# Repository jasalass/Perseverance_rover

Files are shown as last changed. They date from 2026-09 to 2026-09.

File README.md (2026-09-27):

# Rover Percy

🏆 **1er lugar — Torneo Arena IV 2026, Duoc UC** (Desafío de Innovación
CITT-2026, Misión EREBUS-I: Exploración Planetaria).

👥 **Equipo:** Pamela Alvarez y Juan Salas

## 📺 Mira el video

<p align="center">
  <a href="https://youtu.be/7GjuUFy00kE">
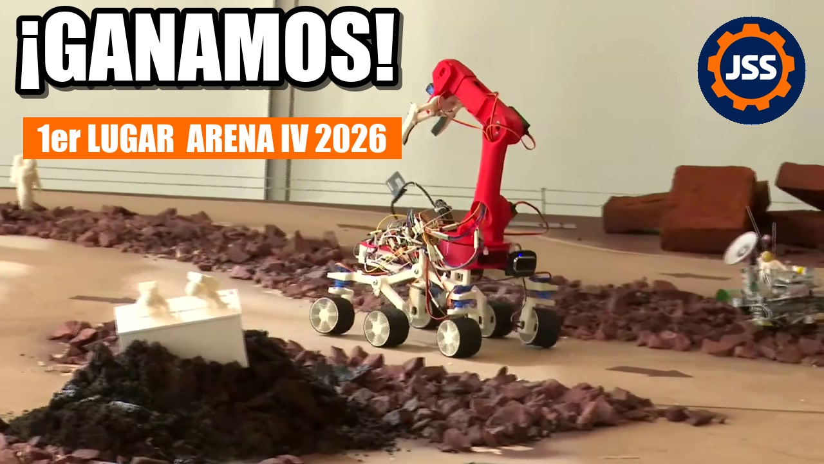
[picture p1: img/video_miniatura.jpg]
Video: Percy compitiendo y la premiación del 1er lugar (clic para ver en YouTube)
    
  </a>
  <br>
  <sub><a href="https://youtu.be/7GjuUFy00kE">Ver en YouTube</a>: Percy en la pista y la premiación.
  Transmisión completa del torneo en el
  <a href="https://www.youtube.com/watch?v=aI01HbEa-U4">canal de Duoc UC</a>.</sub>
</p>

---

## En pocas palabras

Percy es un robot explorador de 6 ruedas inspirado en el rover
*Perseverance* de la NASA. En la competencia tenía que cruzar una pista
de 4×4 m con arena, gravilla y rocas que simula la superficie de Marte,
**recoger muestras con su brazo robótico** y llevarlas a una zona de
depósito, todo en menos de 10 minutos.

<p align="center">
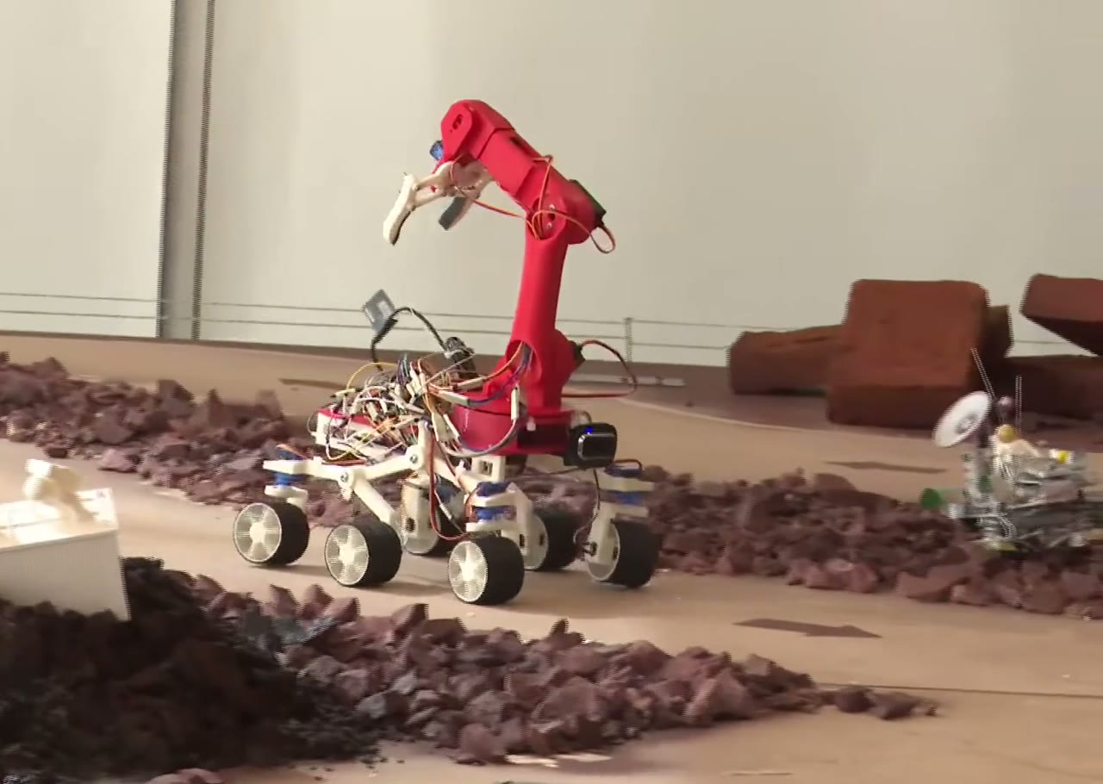
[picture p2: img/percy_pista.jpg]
Percy en la pista de competencia, con la garra abierta
  
</p>

Se maneja **desde el celular**, sin instalar ninguna aplicación: el
robot crea su propia red WiFi, uno se conecta y abre una página web con
dos joysticks táctiles, uno para conducir y otro para mover el brazo.

<p align="center">
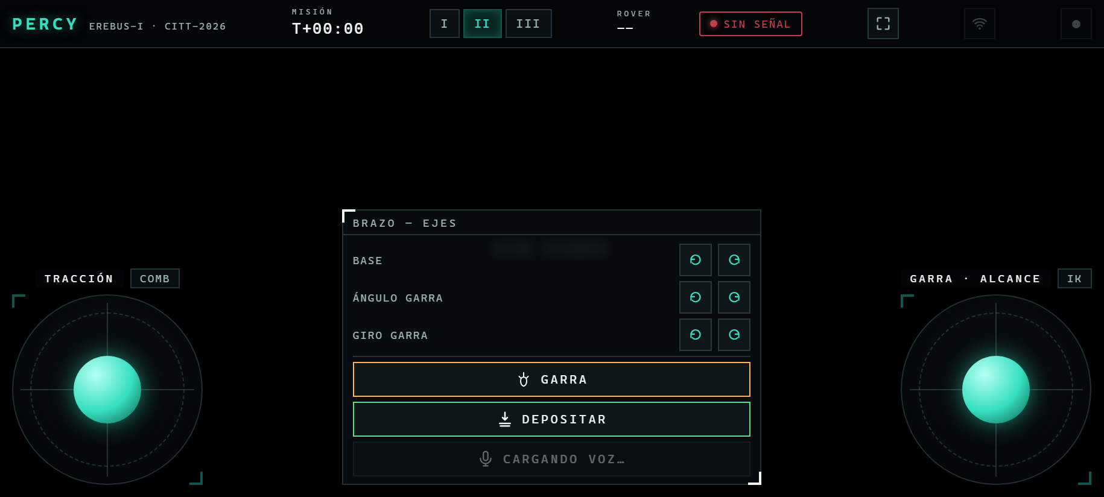
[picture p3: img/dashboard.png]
Dashboard de control en el celular: joystick de tracción a la izquierda, joystick del brazo a la derecha y botones de garra al centro
  
  <br>
  <sub>El panel de control en el celular (horizontal). Joystick izquierdo: tracción. Joystick derecho: punta de la garra. Al centro, los ejes del brazo, la garra y el depósito. El video de la cámara va de fondo.</sub>
</p>

Casi todo el robot está **impreso en 3D**: ruedas, suspensión, chasis y
brazo.

## ¿Cómo funciona?

| Parte | Qué hace |
|---|---|
| **Suspensión rocker-bogie** | El mismo sistema de los rovers reales de Marte: las ruedas suben y bajan por separado, así el robot pasa sobre rocas sin volcarse. |
| **Chasis rediseñado y alargado** | El Percy original no tenía brazo. Alargamos el chasis cerca de un 50% (de 14 a 21 cm) para que el brazo quepa arriba sin desequilibrar el rover, y diseñamos una base nueva que une los dos costados del chasis y sostiene el brazo. |
| **6 ruedas con motor** | Las 6 ruedas empujan, y las 4 de las esquinas además giran para doblar (ver "¿Cómo se desplaza?" abajo). |
| **Brazo robótico con garra** | Gira, sube, baja y se estira para tomar muestras, y las lleva sujetas en la garra hasta la zona de depósito. El operador mueve la punta de la garra con el joystick y el robot calcula solo cómo mover cada articulación. |
| **Computador a bordo** | Una Orange Pi 3B (similar a una Raspberry Pi) recibe las órdenes del celular y controla todos los motores. |
| **Dos baterías separadas** | Una para el computador y otra para los motores, para que un tirón de corriente de los motores no reinicie el computador en plena misión. |

<p align="center">
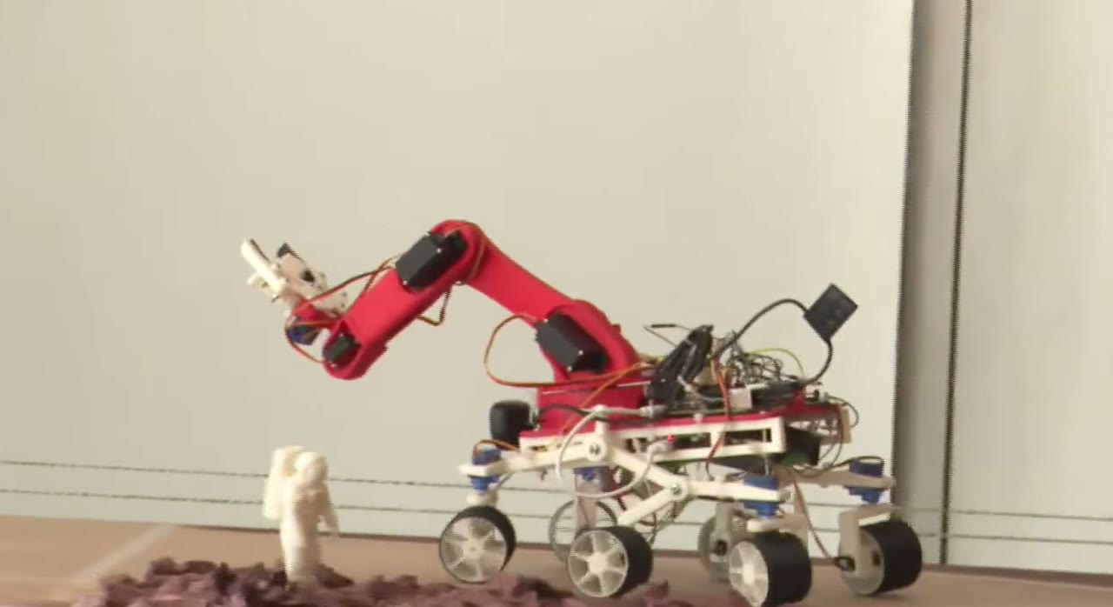
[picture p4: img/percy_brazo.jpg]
Vista lateral de Percy con el brazo extendido
  
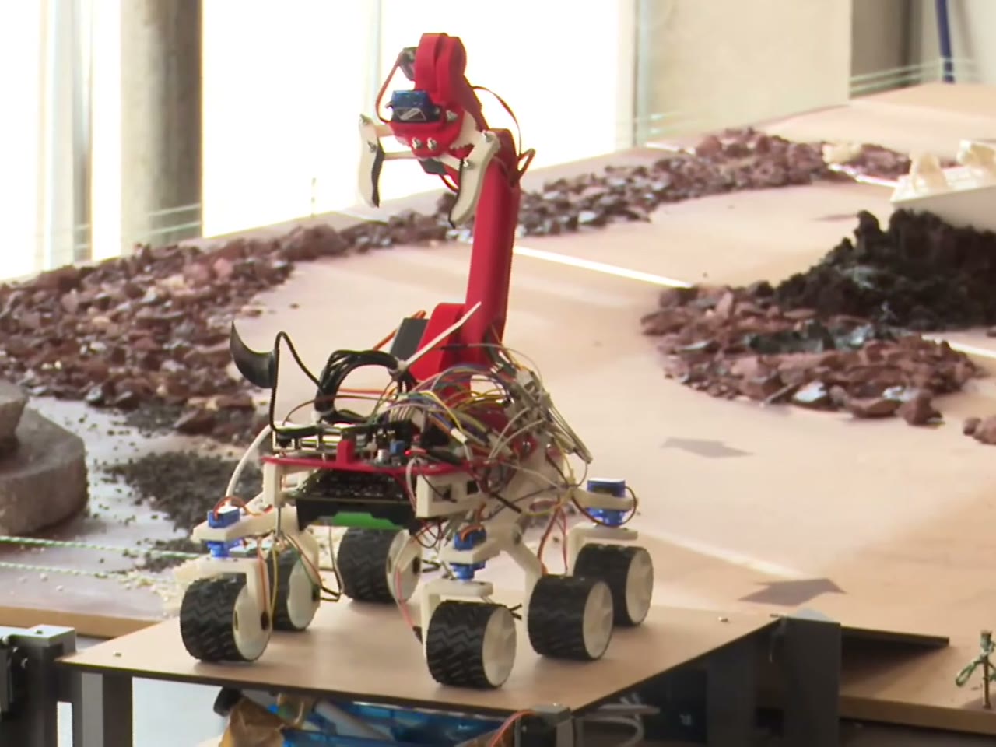
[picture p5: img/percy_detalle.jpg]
Primer plano de Percy: suspensión rocker-bogie, electrónica y brazo
  
</p>

## ¿Cómo se desplaza?

Cada una de las 6 ruedas tiene su propio motor, y las 4 de las esquinas
tienen además un pequeño servo que las hace girar, como el volante de
un auto pero en las dos puntas del robot. Con el joystick izquierdo se
acelera, se frena y se dobla, y un botón del celular cambia entre tres
formas de manejar:

| Modo | Cómo dobla | Para qué sirve |
|---|---|---|
| **Combinado** (el normal) | Gira las ruedas de las esquinas y además hace que un lado avance más rápido que el otro | Uso general: dobla cerrado y firme |
| **Vehículo** | Solo gira las ruedas, como un auto | Arena suelta: las ruedas no se arrastran de costado |
| **Tanque** | Pone las 4 ruedas de las esquinas en diagonal y hace girar cada lado hacia un sentido opuesto | Girar sobre su propio eje sin avanzar, para acomodarse frente a una muestra en poco espacio |

También hay tres velocidades (lenta, media y rápida): la lenta sirve
para acercarse con precisión a una muestra y la rápida para cruzar la
pista.

## Extras de innovación
- El celular **vibra** al agarrar una muestra o cuando el brazo llega a
  su límite.
- **Grabar y reproducir posiciones del brazo:** el operador deja el
  brazo en una posición (por ejemplo, "lista para tomar" o "traslado"),
  la graba con un nombre desde el celular, y después el
  brazo vuelve a ella solo, con un movimiento suave, apretando un botón.
  Ahorra tiempo en las maniobras que se repiten en cada viaje.
- Prototipo de **control por voz** que funciona sin internet, dentro
  del mismo navegador.

---

## Detalle técnico

### Arquitectura

```
Celular (navegador) --WebSocket /ws--> FastAPI (Orange Pi 3B)
                                          |-- I2C  --> PCA9685 --> 10 servos (brazo, garra, steering)
                                          '-- GPIO --> 2x TB6612FNG --> 6 motores N20 (tracción)
```

- **Cómputo:** Orange Pi 3B (RK3566, 4GB) con Ubuntu 22.04 oficial,
  Python + FastAPI + WebSocket. El dashboard es HTML/JS plano, sin
  dependencias externas (en pista no hay internet).
- **Red:** se conecta a redes WiFi conocidas o, si no encuentra
  ninguna, levanta su propia red. Accesible también como `percy.local`.
- **Chasis:** los `side_chassis` originales de BricoLabs (140 mm) se
  reemplazaron por `chasis_largo` (211 mm, ~50% más largos) para ganar
  espacio para el brazo y la electrónica. El brazo se integra con una
  base propia (`base_brazo`, 120×217 mm) que se atornilla sobre los dos
  largueros y reemplaza la `Base.STL` del tutorial; la cintura (`Waist`)
  y el servo de giro se montan encima sin cambios. Piezas en
  `3dprint/stl/rover_perceverance/canasta - chasis nuevo/`.
- **Brazo:** piezas originales del
  [HowToMechatronics](https://howtomechatronics.com/tutorials/arduino/diy-arduino-robot-arm-with-smartphone-control/),
  sin rediseñar, montadas sobre una base propia atornillada al chasis.
  3 servos MG996R (base, hombro, codo) + 1 SG90S con engranajes
  metálicos (inclinación de muñeca) + 2 MG90S (giro y cierre de garra).
  Hombro, codo e inclinación se controlan por cinemática inversa de 3
  juntas acopladas: el joystick mueve la punta de la garra en línea
  recta, no articulación por articulación. También tiene un modo libre
  (articulación por articulación) para calibrar.
- **Presets del brazo:** se graban desde el dashboard con nombre
  (`preset_save`), se reproducen (`preset_goto`) y se borran
  (`preset_delete`) por el mismo WebSocket. Guardan el ángulo final de
  los 5 servos del brazo en `presets.json`, no el trayecto. Al
  reproducirlos, el brazo rampea a 60°/s desde donde esté hasta la pose
  guardada.
- **Dirección:** 4 servos SG90 en las esquinas (±35° en manejo normal),
  con las traseras girando al revés que las delanteras para cerrar el
  radio de giro. 3 modos seleccionables (`drive_mode`): combinado
  (dirección + diferencial entre lados), vehículo (solo dirección) y
  tanque (pivote de radio cero real: ruedas en rombo a 52,5°, ángulo
  calculado de la trocha de 18 cm y la distancia entre ejes de 23,5 cm,
  más diferencial en sentidos opuestos). 3 niveles de velocidad (45%,
  65% y 100% del PWM máximo).
- **Tracción:** 6 motores N20 (1:150) vía 2 puentes H TB6612FNG
  (4 canales, con motores en paralelo por lado), con señal de dirección
  por GPIO y PWM de velocidad por canales libres del PCA9685 (no por los
  2 únicos PWM de hardware de la Orange Pi).
- **Alimentación:** rail de cómputo aislado (2×18650 → módulo 5V USB)
  separado del rail de actuadores (3×18650 → LM2596 → 6V, servos +
  motores), con un interlock por software que corta la tracción
  mientras el brazo se mueve, por el presupuesto de corriente compartido.
- **Control por voz:** Vosk compilado a WebAssembly, 100% en el
  navegador y con gramática cerrada para resistir el ruido de pista.
  Probado offline en PC; en el celular requiere servir el dashboard por
  HTTPS.

### Documentación

- **[`orangepi/README.md`](orangepi/README.md):** protocolo WebSocket,
  tabla de pines y cableado, calibración del brazo, endpoints REST,
  instalación y estructura del código. Incluye una guía de uso del panel
  de control.
- **[`orangepi/voice_models/README.md`](orangepi/voice_models/README.md):**
  cómo generar el modelo de voz para el control por voz.

### Estructura del repo

```
orangepi/       backend (FastAPI, servos, motores, dashboard) - ver su README
3dprint/        piezas STL/gcode del chasis, brazo y ruedas
img/            fotos y capturas usadas en este README
```

## Créditos

- Base mecánica adaptada de [Percy de BricoLabs](https://github.com/felixstdp/Perseverance)
  (rocker-bogie 1:10).
- Brazo del tutorial [DIY Arduino Robot Arm de HowToMechatronics](https://howtomechatronics.com/tutorials/arduino/diy-arduino-robot-arm-with-smartphone-control/).
- Electrónica, software de control y dashboard propios.
- Fotos del rover: fotogramas de la [transmisión oficial de Duoc UC](https://www.youtube.com/watch?v=aI01HbEa-U4)
  del Torneo Arena IV 2026.

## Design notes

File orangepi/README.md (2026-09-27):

# Percy — software de control (Orange Pi 3B)

Esta carpeta es el "cerebro" del rover: el programa que corre en la
Orange Pi y la página web que se abre en el celular para manejarlo. Ver
el [README principal](../README.md) para el contexto del proyecto
(concurso, mecánica, hardware).

## En pocas palabras

- El rover lleva a bordo una **Orange Pi 3B**, un computador del tamaño
  de una tarjeta de crédito (parecido a una Raspberry Pi).
- En ella corre un **servidor web**. Cuando uno abre esa página en el
  celular, aparece un panel de control con joysticks táctiles.
- Cada movimiento del joystick viaja por WiFi al rover unas 20 veces por
  segundo, y la Orange Pi lo convierte en órdenes para los motores de
  las ruedas y los servos del brazo.
- No hace falta instalar ninguna aplicación ni tener internet: basta con
  el navegador del celular.

## Cómo se usa

1. **Encender el rover.** El programa arranca solo; no hay que hacer nada
   más.
2. **Conectar el celular al rover.**
   - En casa, el rover se conecta a las redes WiFi que tenga guardadas.
   - En cualquier otro lugar, si en ~1 minuto no encuentra una red
     conocida, crea su **propia red WiFi, `PercyRover`**.
3. **Abrir el panel** en el navegador del celular:
   - Con la red propia: `http://10.42.0.1:8000`
   - En otra red: `http://percy.local:8000`, o la IP que muestra el aviso
     del rover (ver "WiFi" más abajo).
4. **Poner el celular en horizontal** y manejar con los dos pulgares.

<p align="center">
  Panel de control: joystick de tracción a la izquierda, joystick del brazo a la derecha, botones del brazo al centro
</p>

| Control | Qué hace |
|---|---|
| **Joystick izquierdo** (TRACCIÓN) | Avanza, retrocede y dobla |
| Botón **COMB** junto al joystick izquierdo | Cambia el modo de manejo: combinado, vehículo o tanque (girar en el lugar) |
| **I / II / III** (arriba) | Velocidad lenta, media o rápida |
| **Joystick derecho** (GARRA · ALCANCE) | Mueve la punta de la garra: arriba/abajo y adelante/atrás |
| Botón **IK / LIBRE** junto al joystick derecho | IK: la garra se mueve en línea recta. LIBRE: cada articulación por separado |
| **BASE** | Gira todo el brazo a la izquierda o derecha |
| **ÁNGULO GARRA** | Inclina la garra hacia arriba o abajo |
| **GIRO GARRA** | Gira la garra sobre sí misma |
| **GARRA** | Abre o cierra la garra |
| **DEPOSITAR** | Lleva el brazo a la posición de soltar, abre la garra y vuelve |
| **Micrófono** (VOZ) | Mantener apretado y decir un comando (ver "Control por voz") |
| Ícono de **grabar** (arriba) | Guardar la posición actual del brazo con un nombre, o volver a una guardada |
| Ícono de **WiFi** (arriba) | Ver y cambiar la red del rover |

El celular **vibra** al abrir o cerrar la garra, al depositar y cuando el
brazo llega a su límite.

**Consejos:**
- **Un solo celular conectado a la vez.** Si hay dos, se pisan las
  órdenes (el que está quieto manda "parar").
- **Apagar bien:** `sudo poweroff`, no cortar la batería de golpe. La
  tarjeta SD guarda con retraso y un corte puede perder cambios
  recientes.
- **Cablear siempre con las dos baterías desconectadas.**

---

## Detalle técnico

### Instalación en la Orange Pi

Probado con **Ubuntu 22.04 Server**, imagen oficial de orangepi.org para
la 3B.

```bash
# copiar la carpeta completa a la Orange Pi (desde el PC, con pscp/scp)
pscp -r orangepi orangepi@<ip-orange-pi>:/home/orangepi/percy

# en la Orange Pi
cd ~/percy
pip3 install --user -r requirements.txt   # ver nota en requirements.txt:
                                           # NO instala opencv/gpiod (ya son del sistema)
sudo sh wifi/install.sh                    # gestor WiFi + red propia (ver "WiFi")
```

Después de copiar archivos, correr `sync` antes de apagar.

**Arranque automático (systemd).** El servidor corre como servicio
(`/etc/systemd/system/percy.service`, copia en `percy.service`) y
arranca solo en cada reinicio:

```bash
sudo systemctl status percy.service   # ver estado
sudo systemctl restart percy.service  # reiniciar tras un cambio de codigo
sudo journalctl -u percy.service -f   # ver logs en vivo
```

Tras copiar código nuevo hay que reiniciar el servicio. No lanzar
`python3 main.py` a mano: quedaría un segundo proceso compitiendo por el
puerto 8000.

### Arquitectura y protocolo

```
Celular (navegador) --WebSocket /ws--> FastAPI (main.py)
                                          |-- I2C --> PCA9685 --> 10 servos + PWM de motores (ch10-15)
                                          |                       (brazo x4, giro garra, garra, steering x4)
                                          '-- GPIO --> 2x TB6612FNG --> 6 motores N20 (en paralelo por lado)
```

El dashboard manda ~20 mensajes/seg por WebSocket con el estado completo
de joysticks/botones (no solo cambios). `main.py:_apply_command` traduce
cada mensaje a servos/motores; el servidor responde con un eco liviano
(`{"hit_limit": bool}`) que el dashboard usa para el feedback háptico.

### Tracción — 3 modos (botón de modo del dashboard, `drive_mode`)

| Modo | Cómo gira | Cuándo conviene |
|---|---|---|
| `combinado` (default) | Las 4 ruedas de esquina giran proporcional a `lx` **y** además hay diferencial de velocidad entre lados con el mismo `lx` | Uso general |
| `vehiculo` | Solo dirigen las ruedas de esquina (los 2 lados a la misma velocidad, como un auto) | Terreno suelto: menos desgaste, pero necesita más espacio para girar |
| `tanque` | Diferencial entre lados **+** las 4 ruedas en diagonal, patrón de rombo (ver `servos.set_pivot_steering`) | Pivote de radio cero real, sin arrastrar las ruedas de costado. El ángulo (52,5°) sale de las medidas del chasis (18 cm de trocha, 23,5 cm entre ejes) |

En `combinado`/`vehiculo` las ruedas **traseras giran al revés que las
delanteras**, para cerrar el radio de giro. En `tanque` el rombo es el
mismo para los dos sentidos de giro (se usa `abs(lx)`; el sentido lo pone
el diferencial).

Velocidad: `config.SPEED_LEVELS` multiplica el PWM máximo (45% / 65% /
100%).

### Brazo — cinemática inversa de 3 juntas acopladas

El brazo son las piezas originales del HowToMechatronics, sin rediseñar.
Base, hombro y codo van en MG996R; la inclinación de la muñeca (ch3) va
en un **SG90S con engranajes metálicos**; giro y cierre de garra en
MG90S. Hombro, codo e inclinación quedan en el mismo plano vertical.
`kinematics.solve3(x_mm, y_mm, phi_deg, elbow_up)` calcula los 3 ángulos
de servo necesarios para poner la punta de la garra en esa posición
**con ese ángulo de acercamiento**, no solo esa posición.

Dos modos, elegidos con el switch del dashboard (`arm_mode`):

- **`ik` (default):** el joystick derecho mueve la punta de la garra en
  línea recta (`arm_x_dir`/`arm_y_dir` = velocidad cartesiana, no
  ángulo), y los botones de ángulo de garra mueven el ángulo de
  acercamiento (`wrist_dir` → `phi_dir`). Si el punto pedido no es
  alcanzable, o algún ángulo de servo cae fuera de rango, el objetivo se
  congela en el último punto válido ("pared blanda") en vez de saltar o
  clampear.
- **`joint` (LIBRE):** mismos 3 ejes, pero cada uno mueve su articulación
  por separado (vertical → hombro, horizontal → codo, botones →
  inclinación). Útil para calibrar o alcanzar posiciones que la IK no
  puede.

Si el punto pedido cabe pero el ángulo de acercamiento no (la
inclinación tiene rango corto y suele ser la primera en tocar tope),
**se prioriza la posición de la punta** y se suelta el ángulo lo mínimo
necesario. Además hay una **guarda anti-latigazo**
(`config.IK_MAX_JOINT_STEP_DEG = 8`): una solución que pida mover una
junta más de 8° en un solo tick se rechaza.

**Giro de garra** (canal 4): eje independiente de la IK (girar la garra
no mueve la punta), con sus propios botones (`gripper_rotate_dir`).
Centro en 90°.

Calibración (en `config.py`):

| Junta | Cero (horizontal) | Escala/signo | Rango servo |
|---|---|---|---|
| Hombro (ch1) | 90° | +1 | 45°–175° |
| Codo (ch2) | 68° (horn movido 3 dientes) | −1.19 | 10°–175° |
| Inclinación (ch3, SG90S metálico) | 30° (horn movido 1 diente) | +1 | 5°–135° |
| Giro garra (ch4) | 90° = derecha | — | 10°–170° |

Largos: L1 = 120 mm (medido); **L2 = 115 / L3 = 135 mm estimados** (suman
los 250 mm medidos de codo a punta).

**Presets** (`presets.py`): guardan el ángulo final de los 5 servos del
brazo bajo un nombre, no el camino ni el tiempo. Al pedir un preset
(`preset_goto`), el brazo rampea suave (60°/s) desde donde esté hasta
esos ángulos. `preset_save`/`preset_delete` completan el CRUD;
`/presets` lista los nombres. Quedan en `presets.json`.

**Macro "depositar"** (`servos.deposit_macro`): mueve el brazo a la pose
de depósito (`DEPOSIT_*`), abre la garra y vuelve a la posición de
espera. La muestra viaja en la garra y se suelta directo en la zona de
depósito. Bloqueante, en 3 pasos fijos, sin coordinación con la IK.

### Interlock brazo/tracción

Los 3 MG996R del brazo y los 6 N20 de tracción comparten el mismo riel
de 6V (LM2596 + 3×18650), sin margen de corriente medido para mover los
dos a fondo a la vez. Mientras el brazo esté pedido a moverse, todavía
decelerando, o un preset/macro de depósito esté en curso, `main.py`
fuerza la potencia de los N20 a 0 (la dirección sigue funcionando: son
SG90 de bajo consumo). Expuesto en `/status` como `arm_busy`.

### Feedback háptico

El dashboard vibra el celular al cerrar/abrir garra, disparar el
depósito, reconocer un comando de voz, y en el flanco ascendente de
`hit_limit` (el brazo empujando contra un límite: pared blanda de la IK
o tope de articulación en modo LIBRE).

### Control por voz

Reconocimiento de voz **100% local en el navegador** (Vosk compilado a
WebAssembly, `vosk-browser`): el audio nunca sale del celular ni depende
de internet. Es un modelo acústico real (TDNN); lo que lo hace robusto
al ruido de pista es una **gramática cerrada** en vez de reconocimiento
abierto. Solo puede decidir entre estas 7 frases:

```
"abrir garra", "cerrar garra", "depositar",
"posicion inicial", "traslado", "parar", "alto"
```

Push-to-talk (mantener apretado el botón, no "siempre escuchando"):
`getUserMedia` abre el micrófono → `AudioContext`/`ScriptProcessor`
cortan el audio en bloques de 4096 muestras → `KaldiRecognizer` en
tiempo real → si el resultado final coincide exacto con una frase,
dispara la acción (grip, deposit, preset_goto, o "parar", que corta
joysticks y botones de eje).

**Requisitos:** `getUserMedia` exige HTTPS o `localhost` (ver "HTTPS"),
y el modelo (`model.tar.gz`, ~40MB) tiene que estar en `static/voice/`.
Cómo generarlo: [`voice_models/README.md`](voice_models/README.md).
Probado offline en PC.

### Cableado de motores N20

Cada placa TB6612FNG tiene su **propio** par IN1/IN2 por GPIO dedicado y
su propio canal PWM en el PCA9685 (`servos.set_motor_pwm`, escritura
cruda por registro porque `adafruit_pca9685.duty_cycle` tira `TypeError`
en esta combinación de SO/versión). La Pi solo tiene 2 PWM de hardware
reales, por eso el PWM de motores va por el PCA9685.

- **2 placas TB6612FNG** (4 canales) para los 6 motores. Se usan 3 de
  los 4 canales; el canal B de la placa 2 queda libre.
- **Motores cableados cruzados:** canal **A (AO) = motores derechos**,
  canal **B (BO) = motores izquierdos**. Se corrige en `config.py` (el
  lado izquierdo usa los pines del canal B), sin recablear.
- **Motores en paralelo por lado** (todos los de un lado reciben siempre
  el mismo comando):

| Salida | Motores |
|---|---|
| Placa 1, BO1/BO2 | izquierdos (delantero, central y trasero) |
| Placa 1, AO1/AO2 | derecho delantero |
| Placa 2, AO1/AO2 | derecho central + derecho trasero |
| Placa 2, canal B | libre |

**Señales (pines físicos del header):**

| Señal | Placa 1 | Placa 2 |
|---|---|---|
| AIN1 / AIN2 (derecha) | 11 / 12 | 26 / 31 |
| PWMA | PCA9685 ch10 | ch11 |
| BIN1 / BIN2 (izquierda) | 13 / 15 | 35 / (40, sin conectar) |
| PWMB | PCA9685 ch13 | ch14 |
| STBY | pin 16 (puenteado) | pin 16 (puenteado) |
| VCC lógica | pin 17 (puenteado) | pin 17 (puenteado) |
| VM | +6V del LM2596 | +6V del LM2596 |
| GND | tierra de potencia (estrella) | tierra de potencia (estrella) |

`config.py` define un tercer juego de líneas (pines 29/33/36/38, PCA9685
ch12/15) del diseño original de 3 placas. El software las sigue
manejando, pero no hay nada conectado ahí y no afecta.

**Revisión de la Orange Pi:** según la revisión de la placa, el **pin
físico 26** puede ser GPIO126 o GPIO135. Si se cambia de Orange Pi,
correr `gpio readall` y comparar antes de conectar.

**Tierra:** los GND de las placas van a la tierra de potencia (negativo
del LM2596), no a los pines GND de la Pi. Si se suelta el negativo de
los motores, no gira ninguno.

Si un motor gira al revés que sus compañeros de lado, invertir sus 2
cables en el borne en vez de tocar el software.

Trade-off aceptado: el PWM de motor corre a 50Hz (frecuencia fija del
PCA9685, compartida con los servos), así que puede zumbar un poco a
velocidad baja.

### WiFi: redes conocidas + red propia de respaldo

- Se conecta solo a las redes guardadas en la Pi.
- Si en ~1 minuto no logra conectarse a ninguna, el servicio
  `percy-wifi-watchdog` crea la **red propia `PercyRover`** (clave por
  defecto en `wifi/percy-wifi`, `AP_DEFAULT_PSK`; conviene cambiarla) →
  dashboard en **`http://10.42.0.1:8000`**.
- **Panel WiFi en el dashboard** (protegido con el mismo PIN que las
  posiciones): estado, buscar redes, conectarse (la clave se guarda en la
  Pi), olvidar, desconectar, y activar/apagar la red propia. Cambiar de
  red corta la conexión del celular; el panel avisa a qué red pasarse.
- Si una conexión nueva falla, la Pi vuelve a la red anterior; si tampoco
  puede, crea la red propia. Nunca queda incomunicada.
- **Encontrar el rover en una red nueva** (IP desconocida):
  - **Aviso ntfy:** cada vez que el rover queda en una red (o cambia de
    IP) publica su IP en un canal privado de ntfy; tocar la notificación
    abre el dashboard. El canal lo genera al azar `install.sh` en
    `/etc/percy-wifi-topic` (no está en el repo; se ve en el panel WiFi).
    Necesita internet en esa red.
  - **Nombre fijo:** `http://percy.local:8000` (hostname `percy` +
    avahi). Funciona en PC e iPhone; en Android no siempre.

Implementación: `wifi/percy-wifi` (script sobre `nmcli`, instalado en
`/usr/local/bin` como root; el backend lo llama con una regla `sudo`
acotada a ese único script) + `percy-wifi-watchdog.service`. Instalar con
`sudo sh wifi/install.sh`. Las claves quedan solo en la Pi
(NetworkManager), nunca en el repo. Para agregar una red a mano:
`sudo percy-wifi save "<ssid>" "<clave>"`.

### HTTPS (necesario para el control por voz)

El micrófono del celular (`getUserMedia`) solo funciona en un "contexto
seguro": `https://` o `localhost`. Se usa un certificado autofirmado:
`config.SSL_KEYFILE`/`SSL_CERTFILE` apuntan a `percy.key`/`percy.crt` en
esta carpeta. Si no existen, `main.py` arranca en HTTP plano igual (sin
voz).

Generar el certificado (**rehacerlo si cambia la IP de la Orange Pi**):

```bash
openssl req -x509 -newkey rsa:2048 -nodes -keyout percy.key -out percy.crt -days 825 \
  -subj "/CN=percy.local" \
  -addext "subjectAltName=IP:<ip-orange-pi>,DNS:localhost,IP:127.0.0.1"
```

Copiar `percy.key`/`percy.crt` junto con el resto de la carpeta. La
primera vez que el celular entra a `https://<ip-orange-pi>:8000/`, el
navegador avisa "la conexión no es privada" (normal con un certificado
autofirmado): aceptarlo una vez ("Avanzado" → "Continuar de todas
formas").

### Calibración y seguridad

Todos los pines, canales y ángulos están en `config.py`. Dirección de
las 4 esquinas: `STEER_CENTER = {"fl":85,"fr":90,"rl":85,"rr":95}`.

**Failsafe:** con `config.FAILSAFE_ENABLED = True`, si pasan ~500 ms sin
mensajes del dashboard se detienen los motores. En el repo está en
`False` para poder calibrar por curl/SSH sin el dashboard abierto:
**ponerlo en `True` antes de manejar el rover**.

### Estructura

- `config.py` - todos los pines, canales y ángulos en un solo lugar.
- `servos.py` - PCA9685: 10 servos (brazo x4, giro garra, garra,
  steering x4) por ángulo, más `set_motor_pwm` (PWM crudo de motor,
  ch10-15).
- `kinematics.py` - cinemática inversa del brazo: `solve()` (2 juntas,
  histórico) y `solve3()` (3 juntas acopladas, la que usa `main.py`).
- `presets.py` - guardar e ir a posiciones nombradas del brazo
  (`presets.json`).
- `motors.py` - 6 motores N20 vía 2x TB6612FNG (GPIO de dirección por
  placa + PWM por PCA9685).
- `camera.py` - stream MJPEG de la cámara USB (no rompe nada si no hay
  cámara).
- `main.py` - FastAPI, WebSocket `/ws`, failsafe, interlock
  brazo/tracción; sirve `static/`.
- `static/` - dashboard (2 joysticks, botones, control por voz; ver
  `app.js`).
- `wifi/` - gestor de redes y red propia de respaldo.
- `voice_models/` - cómo generar el modelo de voz y pruebas locales.

### API

#### WebSocket `/ws`

Mensaje del cliente (todos los campos opcionales, default 0/false):

```json
{
  "lx": -0.8, "ly": 0.6, "speed": 1, "drive_mode": "combinado",
  "arm_mode": "ik", "arm_x_dir": 0, "arm_y_dir": 0, "wrist_dir": 0,
  "base_dir": 0, "gripper_rotate_dir": 0, "grip": 0, "deposit": 0,
  "preset_save": null, "preset_goto": null, "preset_delete": null
}
```

Respuesta del servidor (eco liviano, una vez por mensaje recibido):

```json
{"hit_limit": false}
```

#### REST

| Endpoint | Uso |
|---|---|
| `GET /status` | failsafe, cámara disponible, `arm_mode`, `drive_mode`, `arm_busy`, `preset_moving` |
| `GET /servos` | ángulos actuales de cada servo nombrado + si está en modo simulado |
| `GET /presets` | nombres de presets guardados |
| `GET /video` | stream MJPEG de la cámara (si hay) |
| `GET /debug/set_angle?channel=&angle=` | mover un canal puntual. **Solo calibración manual, sin auth** |
| `GET /debug/preset_save?name=` | guardar preset actual sin pasar por el dashboard |

### Limitaciones conocidas y mejoras futuras

- Failsafe desactivado por defecto en el repo (ver "Calibración y
  seguridad").
- Largos L2/L3 de la IK estimados, no medidos.
- Control por voz probado offline en PC, no en el celular real.
- Sensores ToF VL53L0X e IMU MPU-9250 (navegación asistida): pines
  reservados en `config.py`, código no escrito.
- La macro "depositar" es bloqueante.
- Rail de 6V sin fusible, interruptor general ni condensadores.

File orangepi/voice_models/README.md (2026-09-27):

# Modelo de voz (control por voz)

## En pocas palabras

Percy puede recibir algunas órdenes habladas, como "abrir garra" o
"parar", además de los joysticks. El reconocimiento de voz funciona
**dentro del navegador del celular, sin internet**: el audio nunca sale
del teléfono.

Para eso el navegador necesita un **modelo de voz**, un archivo que
"sabe" reconocer español hablado. Pesa unos 40 MB, así que no se guarda
en el repositorio: hay que descargarlo y prepararlo una vez con los
pasos de abajo.

Para robustez frente al ruido, el rover solo escucha 7 frases:

```
"abrir garra", "cerrar garra", "depositar",
"posicion inicial", "traslado", "parar", "alto"
```

Se usa manteniendo apretado el botón del micrófono en el panel de
control mientras se dice el comando.

---

## Detalle técnico

### Generar el modelo

Modelo [Vosk](https://alphacephei.com/vosk/models) pequeño en español
(`vosk-model-small-es-0.42`), empaquetado como `.tar.gz` para
`vosk-browser`:

```bash
curl -L -o vosk-model-small-es.zip https://alphacephei.com/vosk/models/vosk-model-small-es-0.42.zip
unzip vosk-model-small-es.zip
tar -czf model.tar.gz vosk-model-small-es-0.42
cp model.tar.gz ../static/voice/model.tar.gz
```

Después, copiar `static/voice/model.tar.gz` a la Orange Pi junto con el
resto de la carpeta `orangepi/`.

### Requisito: HTTPS

El navegador solo da acceso al micrófono en un contexto seguro
(`https://` o `localhost`). Servido por `http://<ip>:8000`, el botón de
voz falla con "SIN PERMISO DE MIC". Ver la sección "HTTPS" de
[`orangepi/README.md`](../README.md) para generar el certificado
autofirmado.

### Archivos de esta carpeta

- `test_page.html` + `test_voice.py`: pruebas locales, no forman parte
  del dashboard. Sirvieron para validar que Vosk reconoce bien los
  comandos en español antes de integrarlo a `static/app.js`.

Estado: probado offline en PC; pendiente de probar en el celular real
con HTTPS.

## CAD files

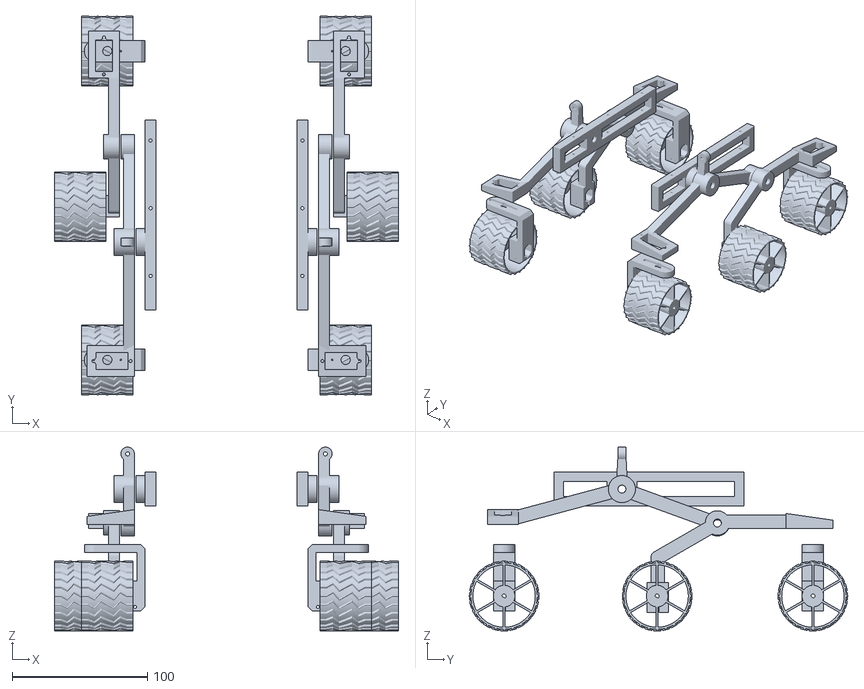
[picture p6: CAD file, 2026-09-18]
3dprint/stl/rover_perceverance/assembly.stl
254.0 x 279.5 x 135.8

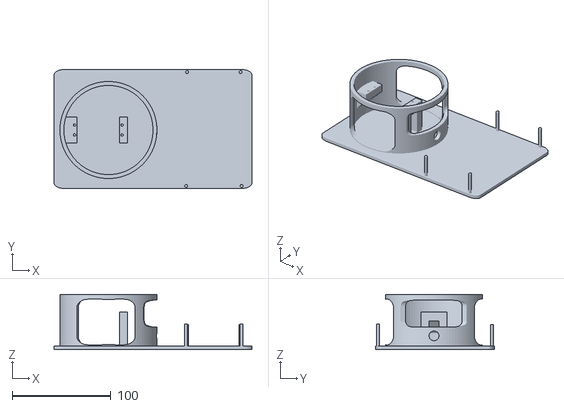
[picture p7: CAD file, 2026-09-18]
3dprint/stl/brazo_howto/bases_descartadas/base_soporte_canasta.stl
200.0 x 120.0 x 56.0

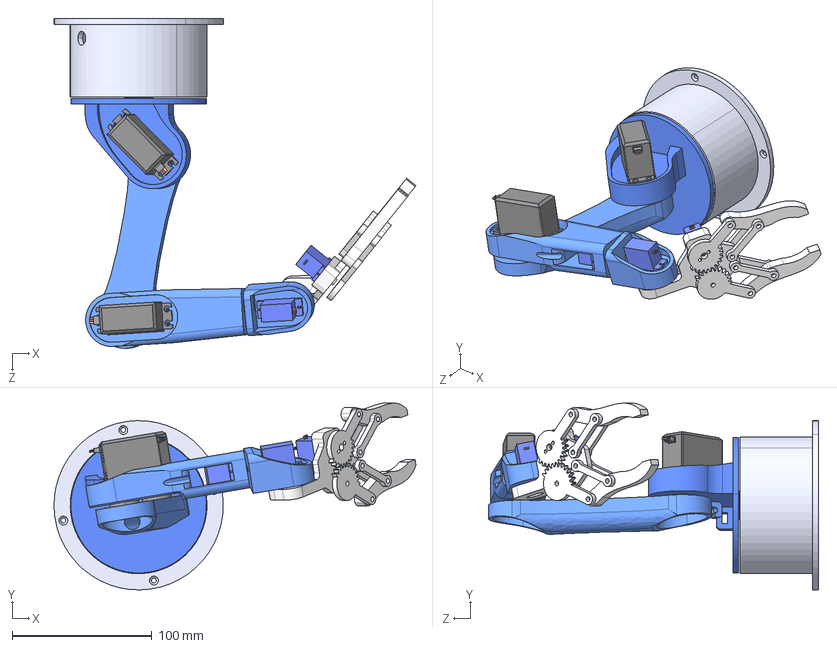
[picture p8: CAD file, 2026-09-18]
3dprint/stl/brazo_howto/Robotic Arm 3D Model.STEP
259.3 x 133.8 x 236.1 mm
Base
Servo Motor MG996R x 3
Waist
Arm 01
Servo Motor Micro 9g x 3
Arm 02 v3
Arm 03
gear1
gear2
grip link 1 x 4
Gripper base
Gripper 1 x 2

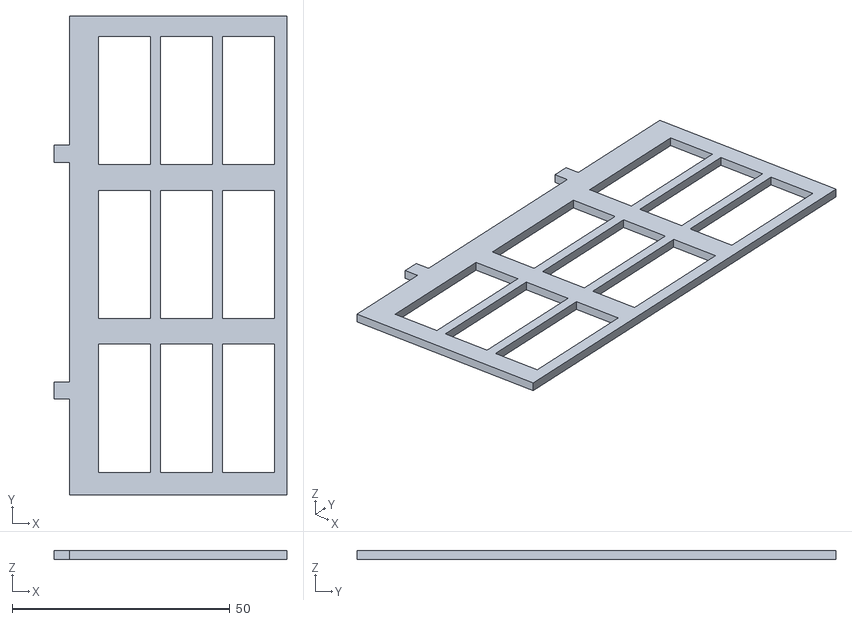
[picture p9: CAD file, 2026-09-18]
3dprint/stl/rover_perceverance/canasta - chasis nuevo/pared_jaula_B X2.stl
53.5 x 110.0 x 2.00

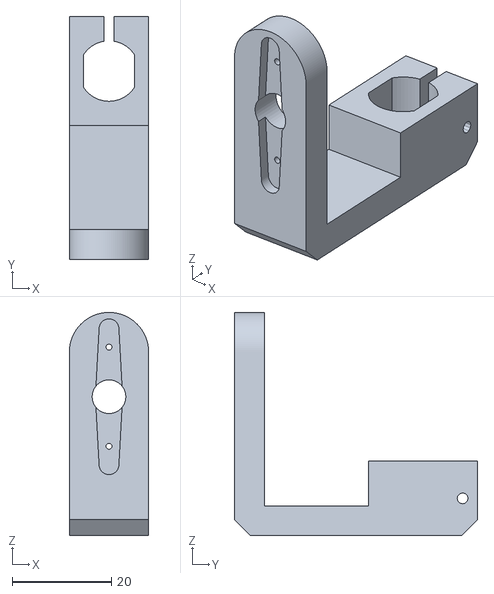
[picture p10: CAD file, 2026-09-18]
3dprint/stl/rover_perceverance/wheel_bracket.stl
16.0 x 49.0 x 45.0

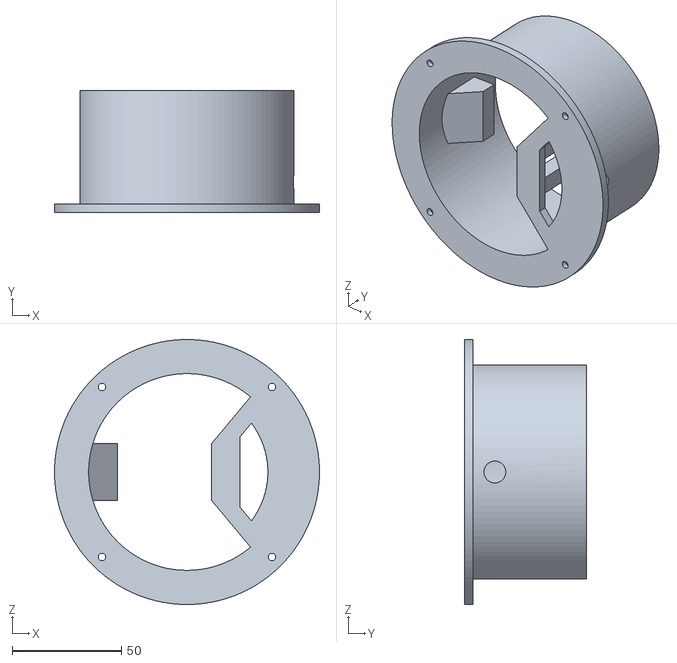
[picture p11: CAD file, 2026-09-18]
3dprint/stl/brazo_howto/bases_descartadas/Base_original.STL
121.2 x 56.0 x 121.2

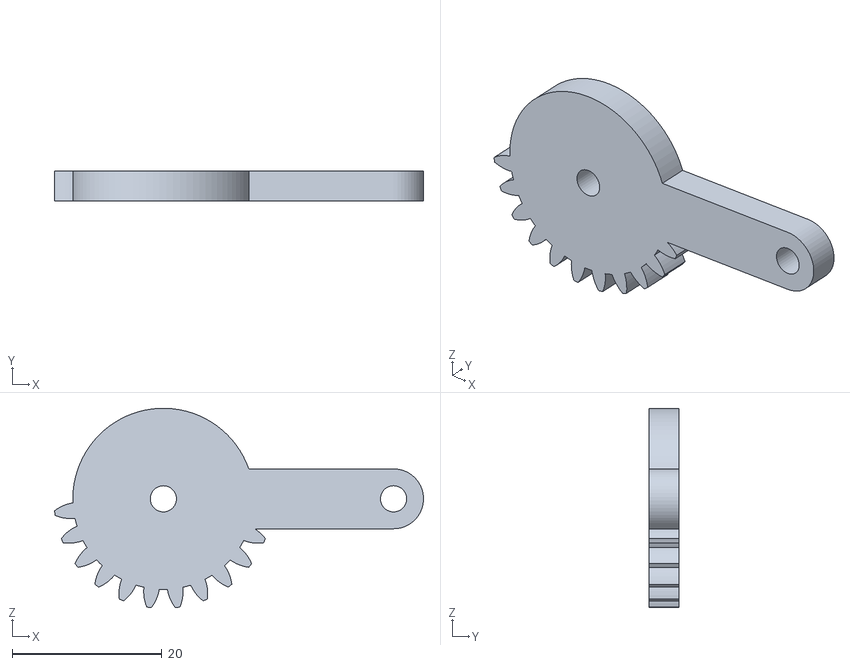
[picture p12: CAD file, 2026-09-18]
3dprint/stl/brazo_howto/gear1.STL
49.3 x 4.00 x 26.6

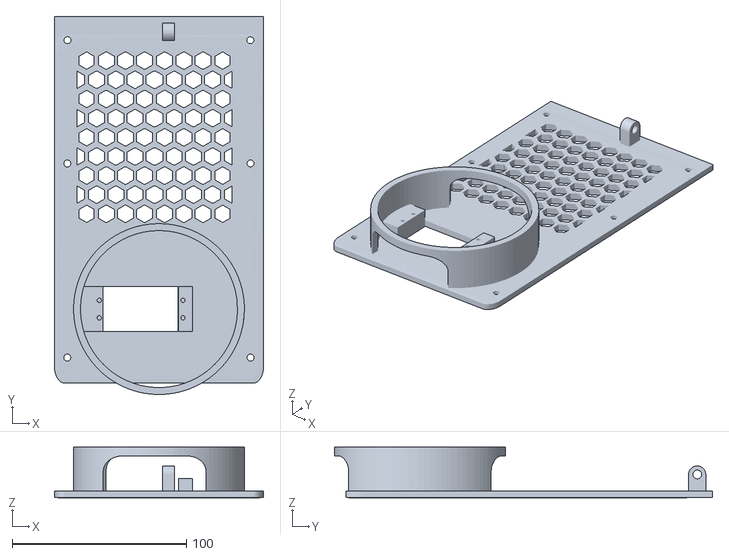
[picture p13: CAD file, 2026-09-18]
3dprint/stl/rover_perceverance/canasta - chasis nuevo/base_brazo (1).stl
120.0 x 216.8 x 29.1

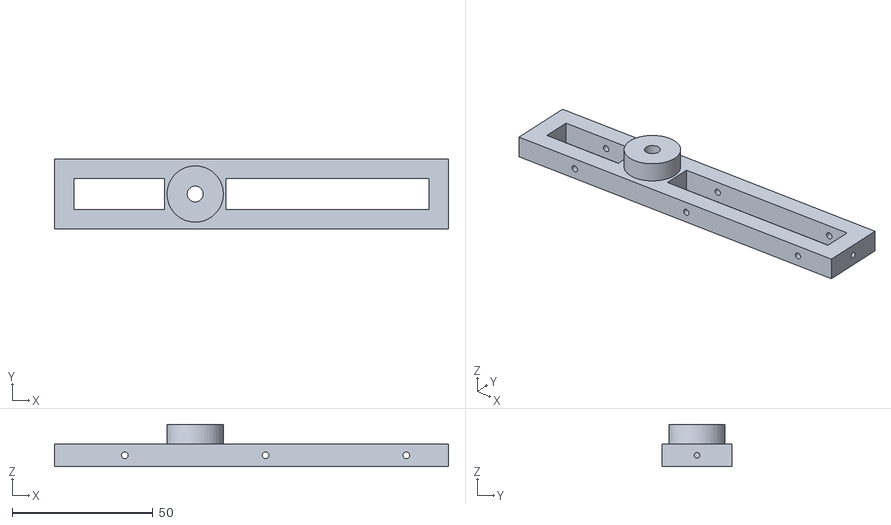
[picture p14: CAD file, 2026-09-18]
3dprint/stl/rover_perceverance/side_chassis.stl
140.0 x 25.0 x 15.0

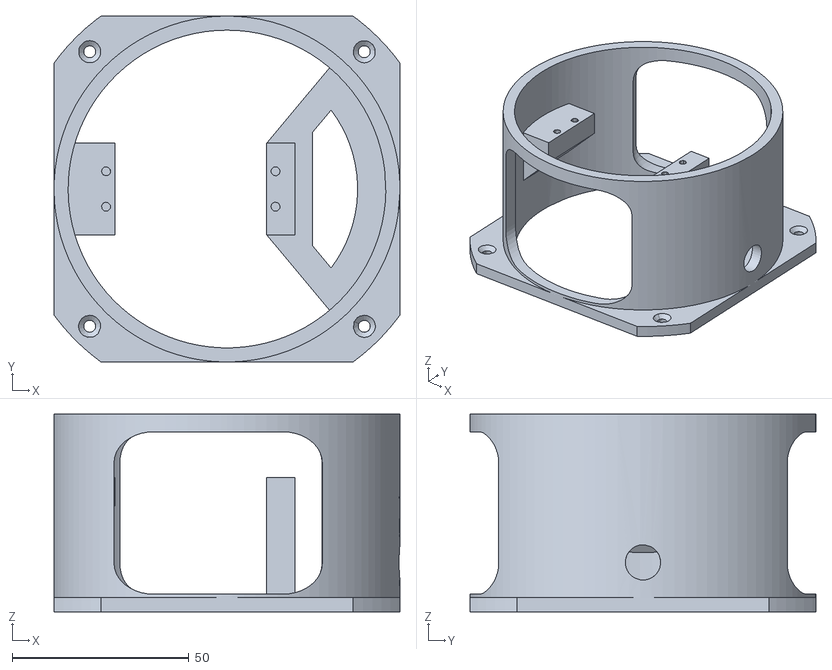
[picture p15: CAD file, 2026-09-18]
3dprint/stl/brazo_howto/bases_descartadas/base_sin_paredes.stl
98.0 x 98.0 x 56.0

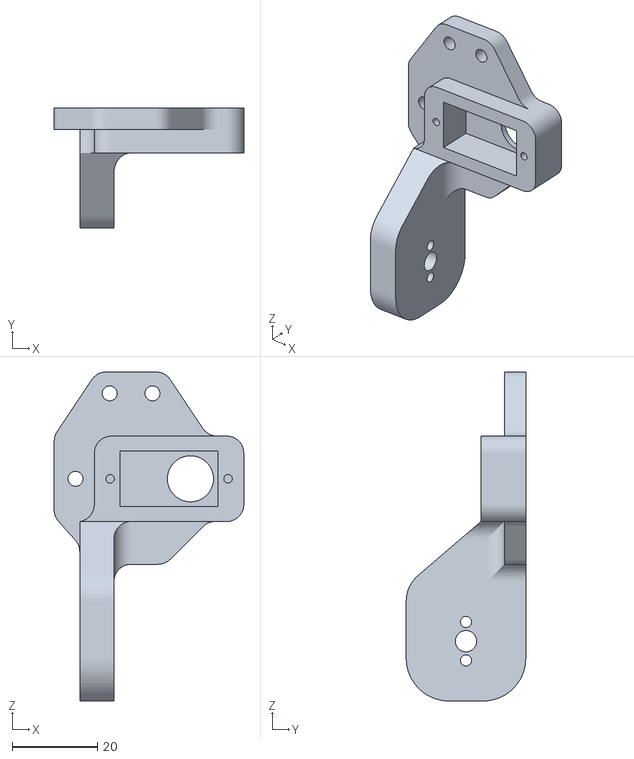
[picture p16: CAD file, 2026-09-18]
3dprint/stl/brazo_howto/Gripper base.STL
44.4 x 28.0 x 77.0

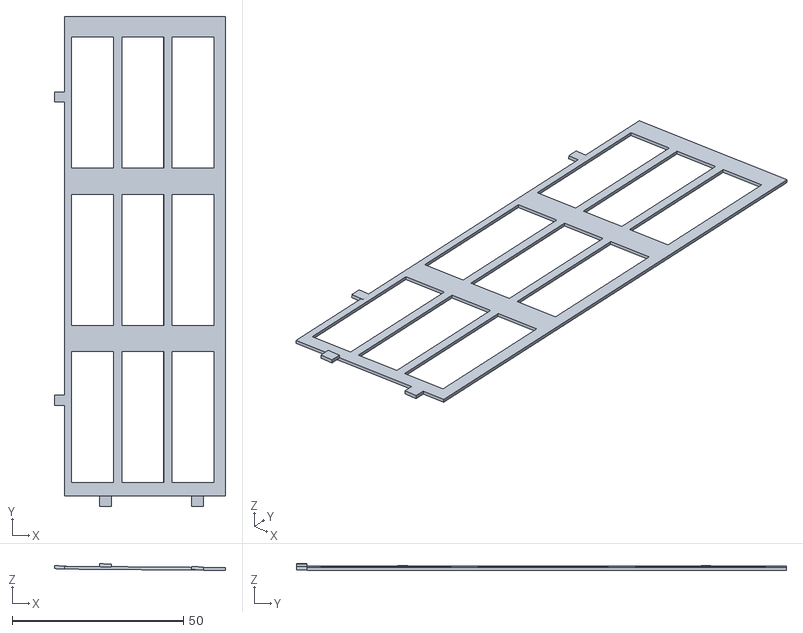
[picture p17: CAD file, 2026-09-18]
3dprint/stl/rover_perceverance/canasta - chasis nuevo/pared_jaula X2.stl
50.0 x 143.0 x 2.00

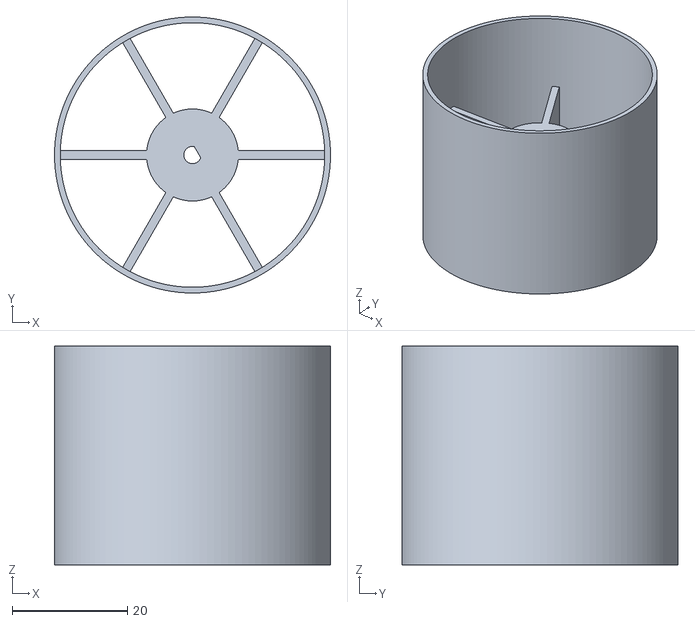
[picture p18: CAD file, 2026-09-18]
3dprint/stl/rover_perceverance/wheel_rim.stl
48.0 x 48.0 x 38.0

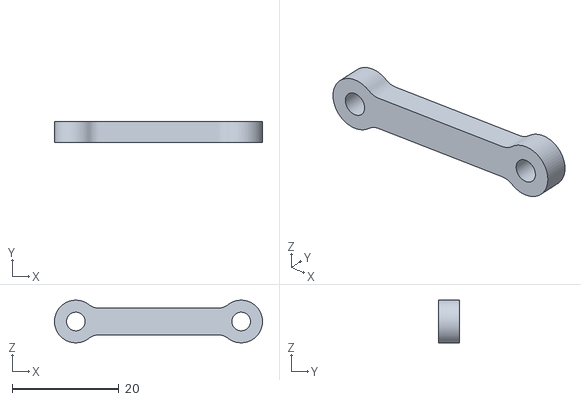
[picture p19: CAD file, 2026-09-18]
3dprint/stl/brazo_howto/grip link 1.STL
39.0 x 4.00 x 8.00

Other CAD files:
3dprint/stl/rover_perceverance/canasta - chasis nuevo/base_jaula.stl
3dprint/stl/rover_perceverance/rear_atrezzo.stl
3dprint/stl/brazo_howto/gear2.STL
3dprint/stl/rover_perceverance/canasta - chasis nuevo/chasis_largo X2.stl
3dprint/stl/brazo_howto/Arm 01.STL
3dprint/stl/brazo_howto/Arm 02 v3.STL
3dprint/stl/brazo_howto/Arm 03.STL
3dprint/stl/brazo_howto/Gripper 1.STL
3dprint/stl/brazo_howto/Waist.STL
3dprint/stl/brazo_howto/base_bisagra.stl
3dprint/stl/rover_perceverance/base_gopro.stl
3dprint/stl/rover_perceverance/front_bogie.stl
3dprint/stl/rover_perceverance/gopro.stl
3dprint/stl/rover_perceverance/rc_support.stl
3dprint/stl/rover_perceverance/rear_bogie.stl
3dprint/stl/rover_perceverance/rtg_cover.stl
3dprint/stl/rover_perceverance/stabilizing_bar.stl
3dprint/stl/rover_perceverance/tyre.stl

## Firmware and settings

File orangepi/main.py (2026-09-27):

"""
Percy - servidor de control (Orange Pi 3B).

FastAPI + WebSocket recibe el JSON de control del dashboard (celular),
traduce a PCA9685 (servos) y GPIO/PWM (motores TB6612FNG). Sirve tambien
el dashboard estatico y el stream MJPEG de la camara.

Correr con:
    uvicorn main:app --host 0.0.0.0 --port 8000
"""
import asyncio
import json
import logging
import math
import time

from fastapi import FastAPI, Request, WebSocket, WebSocketDisconnect
from fastapi.responses import StreamingResponse
from fastapi.staticfiles import StaticFiles

import config
import kinematics
from camera import CameraStream
from motors import MotorController
from presets import PresetManager
from servos import ServoController

logging.basicConfig(level=logging.INFO, format="%(asctime)s %(name)s %(levelname)s %(message)s")
log = logging.getLogger("percy.main")

app = FastAPI(title="Percy Rover Control")


@app.middleware("http")
async def no_cache(request, call_next):
    """El dashboard esta en desarrollo activo y el celular de campo cachea
    agresivamente (ya causo que se viera roto con CSS viejo + HTML nuevo
    mezclados) - se desactiva el cache por completo, no hay ningun beneficio
    de rendimiento real en una app de un solo operador en la red local."""
    response = await call_next(request)
    response.headers["Cache-Control"] = "no-store, no-cache, must-revalidate"
    return response


servos = ServoController()
motors = MotorController(servos)
camera = CameraStream()  # autodetecta el indice por nombre - ver camera.py
presets = PresetManager(servos)

_last_message_ts = time.monotonic()
_failsafe_tripped = False

# Velocidad PEDIDA por el operador (ultimo mensaje WS) vs velocidad ACTUAL
# que de verdad se le manda al brazo - el loop de easing rampea la actual
# hacia la pedida en vez de saltar de golpe (ver _arm_easing_loop abajo y
# config.ARM_MAX_ACCEL_PER_TICK). Sin esto, cada mensaje del joystick
# aplicaba su velocidad instantaneamente -> se sentia brusco/a tirones.
# Hombro/codo/inclinacion ya NO estan aca (18-sept) - pasaron a control
# por IK acoplada, ver _ik_target_vel/_ik_current_vel/_ik_pos mas abajo.
_arm_target = {"base_dir": 0.0, "gripper_rotate_dir": 0.0}
_arm_current = {k: 0.0 for k in _arm_target}

# --- Control del brazo por cinematica inversa --------------------------------
# El joystick derecho mueve la POSICION (x,y) de la punta de la garra en
# linea recta, y los botones que antes eran de la muneca mueven el ANGULO
# DE ACERCAMIENTO (phi) - kinematics.solve3() calcula que angulo de
# hombro/codo/inclinacion hace falta para cumplir las dos cosas a la vez
# (la inclinacion de muneca es un eslabon mas en el mismo plano - ver
# kinematics.py). Mismo patron velocidad+rampa que el
# resto del brazo, integrando x/y/phi en vez de angulos de servo sueltos.
_ik_target_vel = {"x_dir": 0.0, "y_dir": 0.0, "phi_dir": 0.0}  # -1..1 pedido
_ik_current_vel = {k: 0.0 for k in _ik_target_vel}  # -1..1 ya rampeado

# Posicion cartesiana objetivo (mm, origen en el eje del hombro) y angulo
# de acercamiento objetivo (grados, misma convencion que phi_deg en
# solve3). Se sincronizan con la posicion REAL del brazo (via
# kinematics.forward_from_servo/current_phi) recien cuando hace falta, no
# con un valor inventado. _ik_pos_dirty fuerza esa resincronizacion cada
# vez que algo mueve hombro/codo/inclinacion por fuera de este loop
# (preset, macro de deposito, failsafe, debug endpoint) - si no, el
# control por IK seguiria de donde el software CREIA que estaba, no de
# donde el brazo quedo de verdad.
_ik_pos = {"x": 0.0, "y": 0.0}
_ik_phi = 0.0
_ik_pos_dirty = True
# Rama de la solucion IK (codo "arriba" o "abajo", ver kinematics.solve) -
# se recalcula desde la pose real al resincronizar, para no saltar de rama
# sola (ver kinematics.infer_elbow_up).
_ik_elbow_up = True

# Switch IK/LIBRE del dashboard (16-sept): "ik" = joystick derecho mueve la
# punta de la garra en linea recta y los botones mueven phi (ver arriba).
# "joint" = joystick derecho vuelve a mover hombro/codo cada uno por su
# cuenta y los botones mueven la inclinacion directo, sin coordinacion -
# util para calibrar o alcanzar posiciones que la IK no puede (la zona
# muerta del anillo, ver config.py). Mismos campos del joystick/botones
# para los dos modos, el servidor decide que significan segun _arm_mode -
# no hace falta un protocolo distinto.
_arm_mode = "ik"

# Feedback haptico (18-sept): True mientras el brazo esta empujando contra
# un limite (pared blanda de la IK, o tope de articulacion en modo LIBRE) -
# se manda de vuelta al dashboard por WS para que vibre el celular. Flanco
# ascendente nomas (el frontend vibra en el cambio False->True, no todo el
# rato que se mantiene contra el limite).
_arm_hit_limit = False

# Modo de traccion (18-sept): "combinado" (default) mueve las 4 ruedas de
# esquina Y crea diferencia de velocidad entre lados con el mismo lx a la
# vez - un poco de las dos ventajas en cada giro. "vehiculo" gira SOLO con
# las ruedas de esquina (los dos lados a la misma velocidad, como un auto)
# - menos esfuerzo/desgaste en terreno suelto, pero necesita mas espacio
# para girar. "tanque" combina diferencial entre lados CON las 4 ruedas
# de esquina en diagonal (patron de rombo, cada una apuntando al centro
# del rover - ver servos.set_pivot_steering) - pivote de radio cero SIN
# arrastrar las ruedas de costado, a diferencia de un tanque de oruga
# comun. Geometria calculada con las medidas reales del chasis (ver
# config.PIVOT_STEER_DELTA) y confirmada a mano que el varillaje aguanta.
_drive_mode = "combinado"

# True mientras el interlock brazo/traccion (ver _apply_command) esta
# forzando los N20 a 0 - expuesto en /status nomas para poder confirmar por
# SSH que el corte esta actuando de verdad, sin tener que adivinar por que
# el rover "no responde" al joystick de traccion mientras se mueve el brazo.
_arm_busy = False


def _apply_command(data: dict):
    global _last_message_ts, _failsafe_tripped, _arm_mode, _drive_mode, _arm_busy
    _last_message_ts = time.monotonic()
    _failsafe_tripped = False

    arm_mode = data.get("arm_mode")
    if arm_mode in ("ik", "joint") and arm_mode != _arm_mode:
        _arm_mode = arm_mode
        if arm_mode == "ik":
            # volviendo de LIBRE a IK - releer la pose real en vez de
            # seguir desde el objetivo cartesiano viejo (puede haber
            # cambiado mientras estuvo en modo LIBRE).
            _mark_ik_dirty()

    drive_mode = data.get("drive_mode")
    if drive_mode in ("combinado", "vehiculo", "tanque"):
        _drive_mode = drive_mode

    lx = float(data.get("lx", 0.0))
    ly = float(data.get("ly", 0.0))
    speed = int(data.get("speed", 1))

    # Interlock brazo/traccion (18-sept): los MG996R del brazo y los 6 N20
    # de traccion terminaron compartiendo el mismo riel de 6V (ya no hay
    # power bank aparte aislando el consumo del brazo del de los motores -
    # ver historial de la conversacion) - no hay margen de corriente medido
    # para los dos a fondo al mismo tiempo. Mientras el brazo este pedido a
    # moverse (target de este mensaje) O todavia decelerando de un mensaje
    # anterior (_arm_current/_ik_current_vel, el easing loop no llega
    # instantaneo a 0) O un preset/deposit este en curso, se fuerza a 0 SOLO
    # la potencia de los N20 (left/right mas abajo) - el steering sigue
    # respondiendo a lx normal (SG90, consumo bajo, no es el problema).
    arm_requested = (
        float(data.get("base_dir", 0)) != 0.0
        or float(data.get("gripper_rotate_dir", 0)) != 0.0
        or float(data.get("arm_x_dir", 0.0)) != 0.0
        or float(data.get("arm_y_dir", 0.0)) != 0.0
        or float(data.get("wrist_dir", 0.0)) != 0.0
    )
    arm_busy = (
        arm_requested
        or any(_arm_current.values())
        or any(_ik_current_vel.values())
        or presets.moving
        or bool(data.get("deposit"))
    )
    _arm_busy = arm_busy

    if _drive_mode == "vehiculo":
        # Solo dirigen las ruedas de esquina - los dos lados a la misma
        # velocidad, sin diferencial. lx NO entra en left/right.
        left = right = ly
        servos.set_steering(lx)
    elif _drive_mode == "tanque":
        # Diferencial entre lados + las 4 ruedas en diagonal (rombo) -
        # pivote real sin arrastrar las ruedas de costado (ver
        # servos.set_pivot_steering). Con lx=0 las ruedas quedan derechas.
        left = ly + lx
        right = ly - lx
        m = max(abs(left), abs(right), 1.0)
        left, right = left / m, right / m
        servos.set_pivot_steering(lx)
    else:  # "combinado" (default)
        left = ly + lx
        right = ly - lx
        m = max(abs(left), abs(right), 1.0)
        left, right = left / m, right / m
        servos.set_steering(lx)

    if arm_busy:
        left = right = 0.0
    motors.set_motors(left, right, speed)

    # El brazo no se mueve aca directo - solo se actualiza la velocidad
    # PEDIDA. _arm_easing_loop es el que de verdad llama a servos.move_arm
    # (base) y kinematics.solve3() (hombro/codo/inclinacion por IK) o
    # servos.move_arm_joint_direct() (modo LIBRE). "wrist_dir" es el mismo
    # campo del protocolo de siempre (los botones que eran de la muneca) -
    # ahora alimenta phi_dir en vez de mover un canal directo.
    _arm_target["base_dir"] = float(data.get("base_dir", 0))
    _arm_target["gripper_rotate_dir"] = float(data.get("gripper_rotate_dir", 0))
    _ik_target_vel["x_dir"] = float(data.get("arm_x_dir", 0.0))
    _ik_target_vel["y_dir"] = float(data.get("arm_y_dir", 0.0))
    _ik_target_vel["phi_dir"] = float(data.get("wrist_dir", 0.0))

    if data.get("grip"):
        servos.toggle_gripper()
    if data.get("deposit"):
        servos.deposit_macro()
        _mark_ik_dirty()

    preset_save = data.get("preset_save")
    if preset_save:
        presets.save_current(str(preset_save))
    preset_goto = data.get("preset_goto")
    if preset_goto:
        asyncio.create_task(_goto_preset_and_resync(str(preset_goto)))
    preset_delete = data.get("preset_delete")
    if preset_delete:
        presets.delete(str(preset_delete))


def _mark_ik_dirty():
    """Hombro/codo se movieron por fuera del loop de IK (preset, macro de
    deposito, failsafe) - la proxima vez que el joystick de IK se use, hay
    que releer la posicion real del brazo en vez de seguir desde el ultimo
    objetivo cartesiano calculado, que ya no es donde esta el brazo."""
    global _ik_pos_dirty
    _ik_pos_dirty = True


async def _goto_preset_and_resync(name: str):
    await presets.goto(name)
    _mark_ik_dirty()


def _ramp(current: float, target: float, max_step: float) -> float:
    diff = target - current
    if abs(diff) <= max_step:
        return target
    return current + (max_step if diff > 0 else -max_step)


def _ik_feasible(result) -> bool:
    # +-0.01 de margen: el viaje angulo->xy->angulo no siempre vuelve exacto
    # (error de punto flotante), sin esto un punto justo en el limite podia
    # rechazarse por una diferencia de 1e-14 grados (ver bug 16-sept).
    eps = 0.01
    if not (
        result.reachable
        and (config.ANGLE_ARM_SHOULDER_MIN - eps) <= result.shoulder_angle_raw <= (config.ANGLE_ARM_SHOULDER_MAX + eps)
        and (config.ANGLE_ARM_ELBOW_MIN - eps) <= result.elbow_angle_raw <= (config.ANGLE_ARM_ELBOW_MAX + eps)
        and (config.ANGLE_ARM_TILT_MIN - eps) <= result.tilt_angle_raw <= (config.ANGLE_ARM_TILT_MAX + eps)
    ):
        return False
    # Guarda anti-salto (ver config.IK_MAX_JOINT_STEP_DEG): una solucion
    # valida pero lejos de donde estan los servos es un latigazo, no un paso.
    limit = config.IK_MAX_JOINT_STEP_DEG
    return (
        abs(result.shoulder_angle - servos.get_angle(config.CH_ARM_SHOULDER)) <= limit
        and abs(result.elbow_angle - servos.get_angle(config.CH_ARM_ELBOW)) <= limit
        and abs(result.tilt_angle - servos.get_angle(config.CH_ARM_WRIST)) <= limit
    )


def _solve_ik(x: float, y: float, phi: float, relax_phi: bool):
    """(resultado, phi_usado), o (None, phi) si no hay solucion. Con
    relax_phi=True, si (x,y,phi) no cabe prueba phi +-2, +-4... (hasta 90)
    y se queda con el cambio de angulo mas chico que si funcione."""
    result = kinematics.solve3(x, y, phi, elbow_up=_ik_elbow_up)
    if _ik_feasible(result):
        return result, phi
    if relax_phi:
        for step in range(2, 91, 2):
            for sign in (1, -1):
                candidate = phi + sign * step
                result = kinematics.solve3(x, y, candidate, elbow_up=_ik_elbow_up)
                if _ik_feasible(result):
                    return result, candidate
    return None, phi


async def _arm_easing_loop():
    """Rampea _arm_current/_ik_current_vel hacia sus objetivos a lo sumo
    config.ARM_MAX_ACCEL_PER_TICK por tick, y recien ahi mueve el brazo de
    verdad - esto es lo que da la aceleracion/frenado suave en vez de saltar
    directo a la velocidad pedida por el joystick/boton."""
    global _ik_pos_dirty, _ik_elbow_up, _arm_hit_limit, _ik_phi
    tick_s = 1.0 / config.ARM_EASING_HZ
    while True:
        await asyncio.sleep(tick_s)
        for axis, target in _arm_target.items():
            _arm_current[axis] = _ramp(_arm_current[axis], target, config.ARM_MAX_ACCEL_PER_TICK)
        if any(_arm_current.values()):
            servos.move_arm(
                base_dir=_arm_current["base_dir"],
                gripper_rotate_dir=_arm_current["gripper_rotate_dir"],
            )

        for axis, target in _ik_target_vel.items():
            _ik_current_vel[axis] = _ramp(_ik_current_vel[axis], target, config.ARM_MAX_ACCEL_PER_TICK)

        if _arm_mode == "joint":
            # Modo LIBRE: mismos 3 ejes (x_dir/y_dir/phi_dir), pero
            # interpretados como velocidad de CADA articulacion por
            # separado (sin coordinar) - ver servos.move_arm_joint_direct.
            # Vertical -> hombro, horizontal -> codo, botones -> inclinacion
            # directo (igual mapeo que tenia el control viejo).
            if any(_ik_current_vel.values()):
                _arm_hit_limit = servos.move_arm_joint_direct(
                    shoulder_dir=_ik_current_vel["y_dir"],
                    elbow_dir=_ik_current_vel["x_dir"],
                    tilt_dir=_ik_current_vel["phi_dir"],
                )
            else:
                _arm_hit_limit = False
            continue

        if any(_ik_current_vel.values()):
            if _ik_pos_dirty:
                # Recortar ACA a los limites de seguridad de la IK antes de
                # convertir a (x,y,phi) - si el brazo quedo fuera de ese
                # rango por algo que no lo respeta (un preset, o modo
                # LIBRE), arrancar desde el valor crudo real dejaria el
                # punto de partida ya invalido, y el freeze de mas abajo lo
                # revierte siempre contra si mismo -> el joystick queda
                # trabado para siempre (bug 16-sept, ver ese fix original).
                # Margen chico (no justo al borde) para que el error de
                # punto flotante del viaje angulo->xy->angulo no vuelva a
                # caer del otro lado del limite.
                current_shoulder_servo = max(config.ANGLE_ARM_SHOULDER_MIN + 0.5, min(
                    config.ANGLE_ARM_SHOULDER_MAX - 0.5, servos.get_angle(config.CH_ARM_SHOULDER)))
                current_elbow_servo = max(config.ANGLE_ARM_ELBOW_MIN + 0.5, min(
                    config.ANGLE_ARM_ELBOW_MAX - 0.5, servos.get_angle(config.CH_ARM_ELBOW)))
                current_tilt_servo = max(config.ANGLE_ARM_TILT_MIN + 0.5, min(
                    config.ANGLE_ARM_TILT_MAX - 0.5, servos.get_angle(config.CH_ARM_WRIST)))
                wrist_x, wrist_y = kinematics.forward_from_servo(current_shoulder_servo, current_elbow_servo)
                _ik_elbow_up = kinematics.infer_elbow_up(current_elbow_servo)
                _ik_phi = kinematics.current_phi(current_shoulder_servo, current_elbow_servo, current_tilt_servo)
                phi_rad = math.radians(_ik_phi)
                _ik_pos["x"] = wrist_x + config.IK_L3_MM * math.cos(phi_rad)
                _ik_pos["y"] = wrist_y + config.IK_L3_MM * math.sin(phi_rad)
                _ik_pos_dirty = False

            prev_x, prev_y, prev_phi = _ik_pos["x"], _ik_pos["y"], _ik_phi

            # SHOULDER_DOWN_STEP_SCALE (0.12) YA NO se aplica aca (16-sept):
            # era para el control viejo por articulacion, donde el hombro
            # solo podia acelerar de golpe por gravedad entre un paso grande
            # y el siguiente. Con el objetivo cartesiano moviendose en pasos
            # chicos y continuos (mm/tick, no grados/tick de un joint), ese
            # riesgo es mucho menor - y dejarlo aplicado hacia abajo hacia
            # que bajar tardara ~20s completos desde una posicion alta (se
            # sentia como que "no baja"). Si al bajar se siente a tirones de
            # verdad, se puede reintroducir un factor mas suave (ej. 0.6-0.8)
            # en vez del 0.12 original.
            _ik_pos["x"] += _ik_current_vel["x_dir"] * config.IK_CARTESIAN_SPEED_MM_S * tick_s
            _ik_pos["y"] += _ik_current_vel["y_dir"] * config.IK_CARTESIAN_SPEED_MM_S * tick_s
            _ik_phi += _ik_current_vel["phi_dir"] * config.IK_PHI_SPEED_DEG_S * tick_s

            # Posicion de la punta con PRIORIDAD sobre el angulo de
            # acercamiento (21-sept): si (x,y,phi) no se puede cumplir (la
            # inclinacion, con su rango real corto, suele ser la primera en
            # llegar a su tope), se suelta phi lo minimo necesario en vez de
            # congelar todo - si no, el brazo quedaba trabado desde
            # cualquier pose donde phi ya estaba al limite. Solo se relaja
            # mientras se mueve la punta; si el operador esta moviendo phi
            # con los botones y no cabe, se congela como antes.
            tip_moving = bool(_ik_current_vel["x_dir"] or _ik_current_vel["y_dir"])
            result, phi_used = _solve_ik(_ik_pos["x"], _ik_pos["y"], _ik_phi, relax_phi=tip_moving)
            if result is not None:
                _ik_phi = phi_used
                servos.set_angle(config.CH_ARM_SHOULDER, result.shoulder_angle)
                servos.set_angle(config.CH_ARM_ELBOW, result.elbow_angle)
                servos.set_angle(config.CH_ARM_WRIST, result.tilt_angle)
                _arm_hit_limit = False
            else:
                # "Pared blanda": el punto/angulo pedido no se puede
                # cumplir de verdad (fuera de alcance, o algun angulo de
                # servo necesario cae fuera de su rango real - ver nota
                # 16-sept del bug original con el codo). Si se dejara
                # clampear el angulo de salida nomas, el objetivo interno
                # (_ik_pos/_ik_phi) seguiria alejandose de lo que el servo
                # puede cumplir de verdad, y el brazo "saltaba" al volver a
                # tocar el joystick. Se congela el objetivo en el ultimo
                # punto que si se pudo en vez de eso - no se manda nada
                # nuevo, el brazo se queda quieto ahi.
                _ik_pos["x"], _ik_pos["y"], _ik_phi = prev_x, prev_y, prev_phi
                _arm_hit_limit = True
        else:
            _arm_hit_limit = False


async def _failsafe_watchdog():
    global _failsafe_tripped
    if not config.FAILSAFE_ENABLED:
        log.warning(
            "FAILSAFE DESACTIVADO (config.FAILSAFE_ENABLED=False) - solo para "
            "calibrar por script sin el dashboard. Volver a activar antes de "
            "pista/competencia."
        )
        return
    while True:
        await asyncio.sleep(0.1)
        if not _failsafe_tripped and (time.monotonic() - _last_message_ts) > config.FAILSAFE_TIMEOUT_S:
            motors.failsafe_stop()
            servos.failsafe_stop()
            for k in _arm_target:
                _arm_target[k] = 0.0
                _arm_current[k] = 0.0
            for k in _ik_target_vel:
                _ik_target_vel[k] = 0.0
                _ik_current_vel[k] = 0.0
            _mark_ik_dirty()
            _failsafe_tripped = True


@app.on_event("startup")
async def on_startup():
    camera.start()
    asyncio.create_task(_failsafe_watchdog())
    asyncio.create_task(_arm_easing_loop())
    log.info("Percy listo en http://%s:%s", config.WS_HOST, config.WS_PORT)


@app.websocket("/ws")
async def ws_control(websocket: WebSocket):
    await websocket.accept()
    log.info("Cliente conectado")
    try:
        while True:
            raw = await websocket.receive_text()
            try:
                data = json.loads(raw)
            except json.JSONDecodeError:
                continue
            _apply_command(data)
            # Eco liviano de vuelta (18-sept) - el dashboard lo usa para el
            # feedback haptico (vibrar al tocar un limite del brazo). El WS
            # ya estaba abierto y el cliente ya manda 20 msj/seg, asi que
            # no hace falta polling nuevo para esto.
            await websocket.send_text(json.dumps({"hit_limit": _arm_hit_limit}))
    except WebSocketDisconnect:
        log.info("Cliente desconectado")


@app.get("/video")
async def video_feed():
    if not camera.is_available():
        return {"error": "camara no disponible"}
    return StreamingResponse(
        camera.mjpeg_generator(), media_type="multipart/x-mixed-replace; boundary=frame"
    )


@app.get("/status")
async def status():
    return {
        "failsafe_tripped": _failsafe_tripped,
        "camera_available": camera.is_available(),
        "seconds_since_last_command": round(time.monotonic() - _last_message_ts, 2),
        "preset_moving": presets.moving,
        "arm_mode": _arm_mode,
        "drive_mode": _drive_mode,
        "arm_busy": _arm_busy,
    }
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

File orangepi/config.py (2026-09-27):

"""
Configuracion central de Percy (Orange Pi 3B).

Todos los numeros de pin/canal de este archivo son el UNICO lugar que hay
que tocar si el cableado real termina siendo distinto. Los valores de aqui
salieron de:
  - `gpio readall` corrido en la propia Orange Pi (tabla real de pines).
  - El manual oficial Orange Pi 3B RK3566 User Manual v1.0, seccion 3.16.
  - Las decisiones de CLAUDE.md (mapeo de canales PCA9685, etc.)

Ver CLAUDE.md seccion "Pines / hardware - Orange Pi 3B" para el detalle
de por que se eligio cada pin.
"""

# ---------------------------------------------------------------------------
# I2C
# ---------------------------------------------------------------------------
# Bus del PCA9685: pines fisicos 3 (SDA) / 5 (SCL), overlay i2c2-m1.
I2C_BUS_SERVOS = 2

# Bus de sensores (ToF x3 + IMU): pines fisicos 27 (SDA) / 28 (SCL),
# overlay i2c3-m0. Separado del PCA9685 para no mezclar trafico.
I2C_BUS_SENSORS = 3

PCA9685_ADDRESS = 0x40

# ---------------------------------------------------------------------------
# Servos (PCA9685, 16 canales, se usan 10)
# ---------------------------------------------------------------------------
# Brazo de 5 servos + garra, piezas originales HowToMechatronics sin
# rediseñar (el rediseño planeado el 18-sept - brazo 2+3 fusionados con un
# MG996R en la muneca - no se hizo). La inclinacion de muneca (canal 3)
# INCLINA la garra en el mismo plano que hombro/codo. El giro de garra
# sobre su propio eje (canal 4) es un eje independiente (no entra en la
# IK, no cambia la posicion de la punta), lo mueven botones aparte.
# Ver kinematics.solve3() para la IK de las 3 juntas.
CH_ARM_BASE = 0            # MG996R - girar brazo (base)
CH_ARM_SHOULDER = 1        # MG996R - hombro (subir/bajar brazo)
CH_ARM_ELBOW = 2           # MG996R - codo (extender/recoger alcance)
CH_ARM_WRIST = 3           # SG90S engranajes metalicos (reemplazo del MG90) - inclinacion de garra
CH_GRIPPER_ROTATE = 4      # MG90S - gira la garra sobre su propio eje (giro de muneca)
CH_GRIPPER = 5             # MG90S - abre/cierra la garra

CH_STEER_FL = 6      # SG90 - direccion rueda delantera izquierda
CH_STEER_FR = 7      # SG90 - direccion rueda delantera derecha
CH_STEER_RL = 8      # SG90 - direccion rueda trasera izquierda
CH_STEER_RR = 9      # SG90 - direccion rueda trasera derecha

# La bandeja abatible (CH_TRAY) se saco del diseno final (15-sept) - ya
# no existe fisicamente, no hay canal para ella.

# Rango de actuacion de cada servo (grados). Todos los MG996R/MG90/SG90
# usados aqui son de 0-180 grados tipicos; el ancho de pulso por defecto
# de adafruit_motor/ServoKit (750-2250us) funciona para la gran mayoria de
# clones. AJUSTAR si algun servo se ve entrecortado en los extremos.
SERVO_MIN_PULSE_US = 500
SERVO_MAX_PULSE_US = 2500
SERVO_ACTUATION_RANGE = 180

# Angulos de referencia - PROVISORIOS, calibrar con el brazo armado
# (igual que ya se advertia en la version ESP32 del firmware).
ANGLE_ARM_BASE_CENTER = 90
ANGLE_ARM_SHOULDER_REST = 90
ANGLE_ARM_SHOULDER_MIN = 45  # recalibrado 21-sept con el brazo rearmado (mas abajo roza)
ANGLE_ARM_SHOULDER_MAX = 175  # tope real probado 180 (pose "traslado") - se deja 175 de margen para el joystick
ANGLE_ARM_ELBOW_REST = 90
ANGLE_ARM_ELBOW_MIN = 10
ANGLE_ARM_ELBOW_MAX = 175  # 21-sept: casi recto hacia abajo
# Inclinacion de garra (muneca, canal 3, SG90S metalico) - calibrada
# 21-sept con el servo de reemplazo ya montado.
ANGLE_ARM_TILT_MIN = 5    # 21-sept: fin de carrera del servo (cero en 30, ~25 grados bajo la alineacion)
ANGLE_ARM_TILT_MAX = 135  # 21-sept: tope real medido en 136 (mas alla la garra toca el eslabon 2)
# Giro de garra (canal 4) - valores de la calibracion del 16-sept, a
# RECALIBRAR con el brazo rearmado (21-sept).
ANGLE_GRIPPER_ROTATE_CENTER = 90  # recalibrado 21-sept: garra derecha vista de frente
ANGLE_GRIPPER_ROTATE_MIN = 10
ANGLE_GRIPPER_ROTATE_MAX = 170
ANGLE_GRIPPER_OPEN = 90   # calibrado 16-sept con la garra real
ANGLE_GRIPPER_CLOSED = 0  # calibrado 16-sept con la garra real

# El brazo ya NO se mueve directo desde el mensaje del WebSocket - hay un
# loop de "easing" aparte en main.py (_arm_easing_loop) que corre a
# ARM_EASING_HZ y rampea la velocidad actual hacia la velocidad pedida
# (el joystick/boton), en vez de saltar de golpe. Esto da aceleracion y
# frenado suaves en vez del movimiento "a tirones"/brusco de antes.
ARM_EASING_HZ = 50
# Cuanto puede cambiar la velocidad (-1.0..1.0) del brazo por tick del
# loop de easing. Con 0.08 a 50Hz, pasar de quieto a velocidad maxima
# tarda ~250ms - rampa perceptible pero no lenta. Mas chico = mas suave
# pero mas "flotante"; mas grande = mas directo pero menos suave.
ARM_MAX_ACCEL_PER_TICK = 0.08
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

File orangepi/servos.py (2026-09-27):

"""
Control de los 10 servos del rover via PCA9685 (I2C bus 2, ver config.py).

Usa adafruit-pca9685 + adafruit-motor directo (no ServoKit) para poder fijar
el rango de pulso por canal - los MG996R/MG90/SG90 que tenemos no siempre
responden igual al rango por defecto de ServoKit.
"""
import logging
import time

try:
    from adafruit_extended_bus import ExtendedI2C
    from adafruit_pca9685 import PCA9685
    from adafruit_motor import servo
    import smbus2
    _HARDWARE_LIBS_OK = True
except ImportError:
    # Windows/Mac/dev sin hardware real - modo simulado directo, sin
    # instalar las librerias especificas de Linux (Blinka/PCA9685).
    _HARDWARE_LIBS_OK = False

import config

log = logging.getLogger("percy.servos")


class ServoController:
    def __init__(self):
        self._angles = {}  # ultimo angulo pedido por canal, para telemetria
        self._gripper_closed = False
        self._servos = {}
        self._pca = None
        self.simulated = False

        if not _HARDWARE_LIBS_OK:
            self.simulated = True
            log.warning(
                "Librerias de hardware (Blinka/PCA9685) no disponibles en este "
                "sistema - modo SIMULADO: los angulos se registran pero no se "
                "mueve ningun servo real. Normal en Windows/Mac para pruebas "
                "locales; en la Orange Pi esto no deberia pasar."
            )
            return

        # Reintentos al arrancar (17-sept): si percy.service arranca antes
        # de que el bus I2C/PCA9685 este listo (visto en la practica tras
        # un reboot de la Pi), la deteccion fallaba una sola vez y quedaba
        # en modo SIMULADO hasta el proximo reinicio MANUAL del servicio -
        # aunque el chip respondiera bien segundos despues. Mismo problema
        # que se le arreglo a camera.py, misma solucion.
        start_retries = 5
        start_retry_delay_s = 2.0
        last_exc = None
        for attempt in range(1, start_retries + 1):
            try:
                i2c = ExtendedI2C(config.I2C_BUS_SERVOS)
                self._pca = PCA9685(i2c, address=config.PCA9685_ADDRESS)
                self._pca.frequency = 50  # 50Hz estandar para servos analogicos
                for ch in range(16):
                    self._servos[ch] = servo.Servo(
                        self._pca.channels[ch],
                        min_pulse=config.SERVO_MIN_PULSE_US,
                        max_pulse=config.SERVO_MAX_PULSE_US,
                        actuation_range=config.SERVO_ACTUATION_RANGE,
                    )
                # NO se manda ninguna posicion inicial a proposito (16-sept):
                # el PCA9685 mantiene el ultimo PWM que tenia cada canal por
                # su cuenta, independiente de que el proceso Python se
                # reinicie - mandar "posiciones seguras" aca causaba que el
                # brazo se retorciera de golpe cada vez que arrancaba el
                # servicio, sin importar en que posicion real estuviera. Los
                # servos se quedan quietos donde ya estan hasta que llegue
                # un comando real del dashboard.
                last_exc = None
                break
            except (ValueError, OSError) as exc:
                last_exc = exc
                self._servos = {}
                log.warning(
                    "PCA9685 no responde en el bus (%s, intento %d/%d)",
                    exc, attempt, start_retries,
                )
                if attempt < start_retries:
                    time.sleep(start_retry_delay_s)
        if last_exc is not None:
            self.simulated = True
            log.warning(
                "PCA9685 no responde tras %d intentos (%s) - modo SIMULADO: "
                "los angulos se registran pero no se mueve ningun servo "
                "real. Conecta el PCA9685 y reinicia el proceso para operar "
                "de verdad.",
                start_retries, last_exc,
            )

    def set_angle(self, channel: int, angle: float):
        angle = max(0, min(config.SERVO_ACTUATION_RANGE, angle))
        self._angles[channel] = angle
        if not self.simulated:
            self._servos[channel].angle = angle

    # Registro base de LED0_ON_L en el PCA9685; cada canal ocupa 4 bytes
    # (ON_L, ON_H, OFF_L, OFF_H) a partir de ahi. Se lee crudo por smbus2 en
    # vez de usar adafruit_pca9685.duty_cycle porque esa propiedad tira
    # "TypeError: 'memoryview' object cannot be interpreted as an integer"
    # en esta combinacion de SO/version (ver notas de calibracion 16-sept).
    _PCA9685_LED0_ON_L = 0x06
    _PCA9685_PERIOD_US = 20000.0  # 1/50Hz - self._pca.frequency siempre es 50
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

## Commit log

2026-09-18 Reorganize 3dprint assets and update ESP32 backup firmware
    Moves the printed rover STLs into 3dprint/stl/rover_perceverance/,
    adds the HowToMechatronics arm STLs/GCODE, drops the abandoned custom
    OpenSCAD gripper/arm sources (superseded by the HowToMechatronics
    design), and updates perseverance.ino to match the latest pin/servo
    mapping - kept as the ESP32 fallback plan alongside the Orange Pi pivot.
    [Arm 01.STL, Arm 02 v3.STL, Arm 03.STL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]
2026-09-18 Add Orange Pi 3B control backend and mobile dashboard
    Replaces the ESP32 control path with a FastAPI + WebSocket server on
    the Orange Pi 3B, driving the arm/steering via PCA9685 and traction
    via TB6612FNG, with a phone-optimized "mission control" dashboard
    (joysticks, live video, servo telemetry, named position presets).
    Highlights:
    - servos.py: PCA9685 driver with real-hardware angle readback (falls
    back to the last commanded value only when the chip can't be read),
    startup retry so a slow I2C/USB enumeration doesn't strand the
    service in simulated mode, and no forced "safe position" on start so
    the arm never jerks on a restart.
    - kinematics.py + main.py: 2-link inverse kinematics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
    [camera.py, config.py, kinematics.py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]
2026-09-18 Extend arm IK to 3 coupled joints and add haptic limit feedback
    Mechanical redesign (18-sept): the forearm/wrist pieces are fused into
    one, and the wrist stops twisting - it now tilts in the same plane as
    shoulder/elbow, becoming a third joint (driven by an MG996R instead of
    the old MG90S) instead of a free-spinning axis. The old gripper-rotate
    channel is removed entirely.
    - kinematics.py: solve3()/current_phi() extend the existing 2-link
    solver to a 3-joint arm with independent position (x,y) and approach
    angle (phi) control - the trick is subtracting the last link from the
    target to get an intermediate point, solving that with the unchanged
    2-link solve(), then computing the tilt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
    [config.py, kinematics.py, main.py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]
2026-09-18 Add browser-based offline voice control prototype
    Speech recognition runs entirely client-side (Vosk compiled to
    WebAssembly via vosk-browser, loaded from CDN) - no audio leaves the
    phone, no internet dependency, works with the venue having no network
    at all. A restricted grammar (fixed command list) instead of open
    vocabulary recognition, verified in practice to be far more reliable
    in noisy conditions than free-form transcription.
    - static/index.html + app.js: push-to-talk mic button next to the
    existing garra/deposit actions. Recognized commands map to the exact
    same state fields the touch buttons already set (grip, deposit,
    preset_goto, or zeroing the joystick axes for "parar"/"al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
    [config.py, main.py]
2026-09-18 Add selectable drive modes (combined/vehicle/tank)
    The steering wheels and the left/right motor differential were always
    driven by the same lx value, giving one fixed "blended" turning feel.
    Adds a cycle button next to the traction joystick for three modes:
    - combinado (default, unchanged): both effects from the same lx, like
    before.
    - vehiculo: only the corner wheels steer, both motor sides get equal
    speed - rolls through turns like a car instead of scrubbing sideways,
    better traction/efficiency on loose terrain but needs more room to
    turn.
    - tanque: only left/right differential, corner wheels held centered -
    zero-radius pivot turns, useful in tight spots around rocks, at the
    c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
    [main.py]
2026-09-19 Rewire N20 traction as dedicated GPIO per board, motor PWM via PCA9685
    Each TB6612FNG now gets its own IN1/IN2 pins instead of splicing one Pi
    pin across all 3 boards - motor speed PWM moved from the Pi's 2 native
    hardware channels to 6 free PCA9685 channels (raw register writes, same
    workaround as the angle reader since duty_cycle is broken on this
    Blinka/SO combo). Pins confirmed against a live gpio readall, not
    guessed. Also adds a software interlock so the N20 motors are forced to
    zero power while the arm is moving (servos and motors ended up sharing
    the same 6V rail after the Xiaomi power bank was dropped, with no
    measured current headroom for both at once), and documents all of it in
    R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
    [config.py, main.py, motors.py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]
2026-09-19 Consolidate root README, drop stale fork images and ESP32 backup firmware
    Root README was still the original BricoLabs fork stub (old images,
    description of the abandoned radiocontrol/Arduino design). Rewrote it as
    the actual project entry point - architecture, hardware, current status,
    and pointers to orangepi/README.md and CLAUDE.md for detail. Removed the
    3 illustration images (unused outside that stub) and perseverance.ino -
    the Orange Pi pivot is consolidated enough now (motors, IK, voice, all
    working) that the ESP32 emergency fallback plan is no longer needed.
2026-09-24 Recalibrate arm, fix steering geometry and adapt drive to replacement hardware
    Arm: new zero/scale/limits after re-seating the elbow and tilt horns,
    IK now keeps the tip position by relaxing the approach angle, plus an
    anti-jump guard; gripper rotation (ch4) is back as its own axis.
    Steering: rear corner wheels now counter-steer in vehicle/combined mode
    (all four turned the same way, so the rover crabbed instead of turning),
    and the tank-mode diamond no longer inverts for one turn direction.
    Drive: motors ended up wired with channel A on the right side, one
    TB6612 died and another lost an input, and the replacement Orange Pi
    maps header pin 26 to GPIO126 - config follows the real hardware an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
    [config.py, main.py, servos.py]
2026-09-24 Add WiFi manager: home networks with own-network fallback and dashboard panel
    At home the rover joins its saved networks; anywhere else a watchdog
    brings up its own access point (10.42.0.1) after ~1 minute without a
    connection, so it is always reachable at the competition. A failed
    connection attempt falls back to the previous network or the access
    point. The dashboard gets a PIN-protected WiFi panel next to the presets
    menu (scan, connect, forget, disconnect, access point on/off). All
    network changes go through one root-owned nmcli wrapper allowed by a
    narrow sudo rule; passwords stay in NetworkManager on the Pi, never in
    the repo.
    [main.py]
2026-09-24 Show the rover's current IP in the dashboard header
    Live IP on home networks (polled every 10 s), fixed 10.42.0.1 on the
    rover's own network, and the last IP seen on each network remembered in
    the WiFi panel so it doesn't have to be memorized.
2026-09-27 Rewrite READMEs for technical and non-technical readers after the win
    - Root README: 1st place at Arena IV 2026, competition video, team,
    plain-language overview (how it works, how it drives, innovation
    extras) followed by the technical detail, plus photos and a
    dashboard screenshot in img/.
    - orangepi/README: usage guide for the control panel before the
    technical sections; drop home network names and IP history.
    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
